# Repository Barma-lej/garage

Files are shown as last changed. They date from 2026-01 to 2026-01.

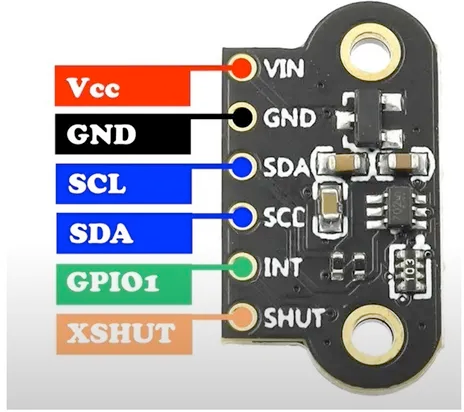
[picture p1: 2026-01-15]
docs/TOF400C-VL53L1X.png

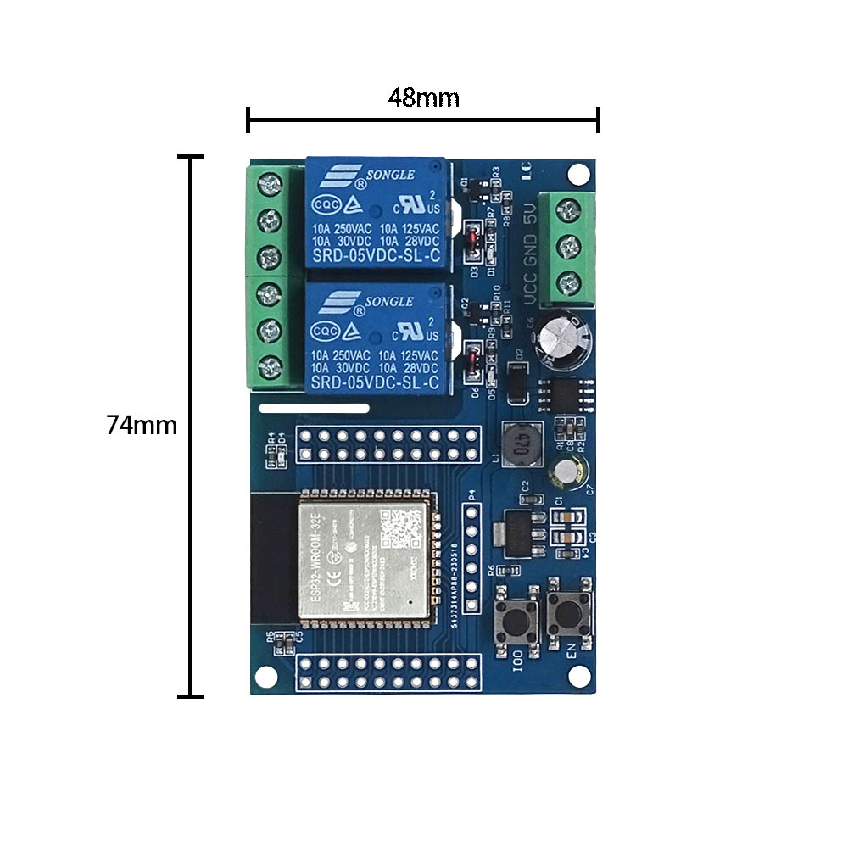
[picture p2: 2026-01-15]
docs/ESP32 Relay x2 (ESP32-WROOM-32E)-2.jpg

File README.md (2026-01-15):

# Smart Garage Door Controller with ESP32






This repository contains the firmware and configuration to transform any Hörmann Promatic 3 garage door opener into a smart, Home Assistant-controllable device. The system uses an **ESP32 Relay x2 (ESP32-WROOM-32E)** smart relay module to relay commands to the garage door drive unit while monitoring door position through a **TOF400C-VL53L1X** time-of-flight distance sensor and closed-position detection via a 24V optocoupler.

---

##  Key Capabilities
- **Remote Control**: Open, close, and ventilate (partial open) your garage door from Home Assistant
- **Position Feedback**: Real-time door position tracking using ToF sensor with millimeter precision
- **Safety Detection**: Closed position confirmation via hardware optocoupler
- **Local Integration**: Fully local control—no cloud dependency
- **Automation Ready**: Trigger automations based on door state and position
- **Voice Control**: Works with Home Assistant voice integrations (Alexa, Google Home)

---

## Hardware Requirements

| Component | Model/Specification | Purpose | Picture |
|---|---|---|---|
| Main controller | ESP32 Relay x2 (ESP32-WROOM-32E) | Main controller, WiFi, Relays (Open/close/airing garage door) | [ESP32 Relay x2 (ESP32-WROOM-32E)](docs/ESP32%20Relay%20x2%20(ESP32-WROOM-32E).jpg) |
| Position Sensor | 1-Channel 24V Optocoupler | Closed-state detection | [1-Channel 24V Optocoupler](docs/1%20Channel%20Way%20Optocoupler%2024V.jpg) |
| Distance Sensor | TOF400C-VL53L1X (I²C) | Position feedback, addr 0x29 | [TOF400C-VL53L1X](docs/TOF400C-VL53L1X.png) |

### Calibration Constants (from garage.yaml)
- **Closed position distance**: 2630 mm (door fully closed, sensor facing floor)
- **Open position distance**: 240 mm (door fully open)
- **Airing position**: 9% (0.09 × 100, triggered by Relay 2 + binary_airing flag)
- **Debounce time**: 50 ms (end_stop_bottom optocoupler)
- **Relay pulse duration**: 800 ms (impulse command activation)

### Optional Components
- 10 kΩ pull-up resistors (for ToF I²C SDA/SCL lines)
- **3D-printed enclosure and sensor mount** — See [3D Models](#3d-models) section for STL files and printing guide

---

## Installation

### 1. Hardware Assembly

#### Wiring Diagram

Wiring Diagram

```
Connections:
━━━━━━━━━━━━━━━━━━━━━━━━━━━━━━━━━━━━━━━━━━
GPIO16  → Relay 1 (Open/close command)
GPIO17  → Relay 2 (Ventilation command)
GPIO21  → TOF400C I²C SDA (optional with 10kΩ pull-up)
GPIO22  → TOF400C I²C SCL (optional with 10kΩ pull-up)
GPIO23  → LED anode (330Ω resistor to GND)
GPIO32  → 24V Optocoupler input (INPUT_PULLUP)
GND     → Common ground (all modules)
5V      → Relay module VCC, ESP32 5V
Vin     → Optional 5V USB power

Hörmann Promatic 3 Control:
━━━━━━━━━━━━━━━━━━━━━━━━━━━━━━━━━━━━━━━━━━
Relay 1 NO contacts  → Hörmann "Open" impulse terminals
Relay 1 NC contacts  → Hörmann "Close" impulse terminals
Relay 2 NO contacts  → Hörmann "Ventilation" impulse terminals
24V common           → Optocoupler cathode
```

---

## 3D Models

The project includes 3D-printable box in [`3D_model/`](3D_model/) directory.

---

## Firmware Upload

### Prerequisites
- **Home Assistant** instance running with ESPHome add-on installed
- **ESPHome Dashboard** web interface accessible (typically port 6052)
- **ESP32-WROOM-32E** connected via USB-C to the computer running Home Assistant
- **Secrets file** (`secrets.yaml`) with required credentials:
  ```yaml
  # secrets.yaml
  wifi_ssid: "Your_WiFi_Name"
  wifi_password: "Your_WiFi_Password"
  fallback_ap_password: "ApFallbackPassword"
  web_server_user: "admin"
  web_server_password: "YourWebPassword"
  garage_api: !secret api_encryption_key  # Generate via ESPHome
  ota_password: "YourOTAPassword"
  ```

### Step-by-Step Upload

1. **Prepare configuration file**
   - Copy the provided [`garage.yaml`](garage.yaml) to your Home Assistant configuration
   - Update GPIO pin assignments if different from your hardware
   - Edit substitution variables (friendly names, sensor calibration values)

2. **Access ESPHome Dashboard**
   - Open Home Assistant → Settings → Add-ons → ESPHome
   - Click "Open Web UI"
   - Ensure you see the ESPHome dashboard interface

3. **Create New Device**
   - Click "+ NEW DEVICE" button
   - Select "Continue"
   - Choose board type: **"ESP32 Dev Kit v1"** or similar
   - Enter device name: `garage` (or your preference)
   - Click "Next" → "Skip"

4. **Upload Configuration**
   - In dashboard, click the device card or **"Edit"** button
   - ⚠️ Copy `ap:` `password:` from auto-generated YAML to your `secrets.yaml` ⚠️
   - Replace the auto-generated YAML with your `garage.yaml` configuration
   - Click **"Save"**
   - ESPHome will validate the configuration

5. **Build & Upload Firmware**
   - Connect ESP32 via USB-C to your Home Assistant host
   - Click **"···" menu** → **"Upload"**
   - Select connection type: **"USB"** (or choose serial port)
   - Wait for compilation (~2–3 minutes) and upload
   - You should see: **`✓ Installed Successfully`**
   - Monitor serial logs during upload for any errors

6. **Verify Installation**
   - Disconnect USB cable (device will connect via WiFi)
   - In ESPHome dashboard, confirm device shows **"Online"** status
   - Go to Home Assistant → Settings → Devices & Services → ESPHome
   - You should see:
     - **Cover entity**: `cover.garage` (or `cover.tor`)
     - **Binary sensors**: `binary_sensor.geöffnet` (opened), `binary_sensor.lüftung` (airing)
     - **Sensors**: Position %, distance (mm), range status
   - Click the device to view detailed metrics

### Alternative: Manual Flashing (Advanced)

If USB connection is unavailable on your Home Assistant instance:

```bash
# Install esphome CLI
pip install esphome

# Compile firmware
esphome compile garage.yaml

# Flash via USB serial adapter
esphome run garage.yaml --device /dev/ttyUSB0 --upload-speed 460800

# View logs
esphome logs garage.yaml
```

---

## Usage

### Home Assistant Interface

Once discovered and configured, the following entities appear:

| Entity ID | Type | Function |
|---|---|---|
| `cover.tor_tor` (or `tor`) | Cover | Main door control with position slider (0–100%) |
| `button.tor_tor` | Button | Trigger open/close impulse |
| `button.tor_luftung` | Button | Trigger ventilation/airing impulse |
| `button.tor_restart` | Button | Restart device |
| `button.tor_safe_mode_boot` | Button | Safe mode boot |
| `binary_sensor.tor_geoffnet` | Binary Sensor | True when door is **open** (optocoupler inactive) |
| `binary_sensor.tor_luftung` | Binary Sensor | True when **ventilation mode** is active |
| `sensor.tor_position` | Sensor | Current door position in % (0=closed, 100=open) |
| `sensor.tor_distanz` | Sensor | Calibrate ToF distance in mm |
| `sensor.tor_raw_distanz` | Sensor | Raw ToF distance in mm |
| `sensor.tor_bereichsstatus` | Text Sensor | Range status (e.g., "Range Valid", "Signal Fail") |
| `sensor.tor_bereichsstatuswert` | Sensor | Range status (e.g., "1", "2") |
| `update.tor_firmware` | Update sensor | True when update is available |

### Control Methods

**Via Home Assistant UI:**
- Click the cover card to **open/close** the door
- Use the **position slider** for precise control:
  - Drag left (<5%) → **Close command**
  - Drag middle (10–20%) → **Ventilation** (9% opening)
  - Drag right (>95%) → **Open command**
- The **stop button** pauses movement

**Via Automations:**
```yaml
automation:
  - alias: "Close garage at night"
    trigger:
      platform: time
      at: "22:00:00"
    condition:
      - condition: state
        entity_id: cover.garage
        state: "open"
    action:
      - service: cover.close_cover
        target:
          entity_id: cover.garage

  - alias: "Open garage when arriving home"
    trigger:
      platform: state
      entity_id: person.john_doe
      to: "home"
    action:
      - service: cover.open_cover
        target:
          entity_id: cover.garage
```

**Via Scripts:**
```yaml
script:
  garage_ventilate:
    sequence:
      - service: cover.set_cover_position
        target:
          entity_id: cover.garage
        data:
          position: 15  # Triggers ventilation (9-20% range)

  garage_open:
    sequence:
      - service: cover.open_cover
        target:
          entity_id: cover.garage
```

**Via Voice Commands** (if Alexa/Google Home linked):
```
"Alexa, open my garage"
"Alexa, close my garage"
"Hey Google, open the garage door"
```

**Via MQTT** (if configured):
```bash
mosquitto_pub -h homeassistant.local -t home/garage/command -m "OPEN"
mosquitto_pub -h homeassistant.local -t home/garage/command -m "CLOSE"
mosquitto_pub -h homeassistant.local -t home/garage/command -m "VENTILATE"
```

---

## Configuration

### ESPHome YAML Configuration (garage.yaml)

The project includes a comprehensive [`garage.yaml`](garage.yaml) configuration file. Key sections:

#### 1. Substitutions (Customizable Variables)
```yaml
substitutions:
  name: garage
  room: Garage
  friendly_name: "Tor"  # German: "Gate"
  project_version: "2025.12.0"
  
  # GPIO Pin Assignments
  relay1_pin: GPIO16       # Open command
  relay2_pin: GPIO17       # Ventilation command
  status_led: GPIO23       # Status LED
  optocoupler_pin: GPIO32  # Closed-position sensor
  sda_pin: GPIO21          # I²C Data (ToF sensor)
  scl_pin: GPIO22          # I²C Clock (ToF sensor)
```

#### 2. WiFi Configuration
```yaml
wifi:
  ssid: !secret wifi_ssid
  password: !secret wifi_password
  fast_connect: true       # Connect quickly to known networks
  ap:
    ssid: "Garage Fallback Hotspot"
    password: !secret fallback_ap_password
```

#### 3. I²C Bus (TOF400C Sensor)
```yaml
i2c:
  - id: bus_a
    sda: GPIO21
    scl: GPIO22
    scan: true
    frequency: 400kHz  # Standard I²C frequency
```

#### 4. Cover Entity (Main Control)
```yaml
cover:
  - platform: template
    id: garage_door_cover
    name: "Tor"  # Display name
    device_class: garage
    has_position: true
    
    # Current position (0.0=closed, 1.0=open)
    lambda: |-
      return id(pos_sensor).state / 100.0;
    
    # Open command (Relay 1 pulse)
    open_action:
      - if:
          condition: lambda: 'return id(pos_sensor).state < 99.0;'
          then:
            - button.press: button_gate
    
    # Close command (Relay 1 pulse)
    close_action:
      - if:
          condition: binary_sensor.is_on: end_stop_bottom
          then:
            - button.press: button_gate
    
    # Position-based control
    position_action:
      - lambda: |-
          if (pos < 0.05) {
            // Close command
            if (id(end_stop_bottom).state)
              id(button_gate).press();
            id(binary_airing).publish_state(false);
          }
          else if (pos > 0.95) {
            // Open command
            if (id(pos_sensor).state < 95.0)
              id(button_gate).press();
            id(binary_airing).publish_state(false);
          }
          else if (pos > 0.10 && pos < 0.20) {
            // Ventilation (9% target)
            id(button_airing).press();
            id(binary_airing).publish_state(true);
          }
```

#### 5. Position Sensor (Lambda Calculation)
The position is calculated with priority logic:
```lambda
if (x != 0) return NAN;  // Validate range status

// 1. HARDWARE END-STOP (highest priority)
if (!id(end_stop_bottom).state)
  return 0.0;  // Door is closed

// 2. VENTILATION FLAG
if (id(binary_airing).state)
  return 9.0;  // Fixed ventilation position

// 3. DISTANCE-BASED CALCULATION
float max_dist = 2630.0;   // Closed (mm)
float min_dist = 240.0;    // Open (mm)
float calculated = ((max_dist - current_dist) / (max_dist - min_dist)) * 100.0;
return constrain(calculated, 0.0, 100.0);
```

### Configuration Customization

**Change GPIO pins:**
```yaml
substitutions:
  relay1_pin: GPIO4      # Change from GPIO16
  relay2_pin: GPIO5      # Change from GPIO17
  optocoupler_pin: GPIO35 # Change from GPIO32
```

**Adjust sensor calibration:**
```yaml
# In the position lambda function:
float max_dist = 2750.0;   # If your closed distance differs
float min_dist = 200.0;    # If your open distance differs
```

**Modify relay pulse duration:**
```yaml
button:
  - platform: output
    id: button_gate
    output: relay1
    duration: 1000ms  # Change from 800ms
```

**Enable debug logging:**
```yaml
logger:
  level: DEBUG  # More verbose output
  
text_sensor:
  - platform: template
    id: range_value
    name: "Range Status"
    disabled_by_default: false  # Show in UI
```

---

## Troubleshooting

### Device Not Connecting to WiFi
- **Symptom**: Fallback hotspot appears, no home network connection
- **Solution**:
  - Verify SSID and password in `secrets.yaml` are correct
  - Check WiFi signal strength in garage (RSSI > -75 dBm ideal)
  - Restart ESPHome device via Home Assistant → Devices → Restart
  - Check logs: ESPHome dashboard → Logs

### Distance Sensor Returns NAN or Invalid Readings
- **Symptom**: ToF sensor shows "NAN" in position sensor, range status is not 0
- **Solution**:
  - Verify I²C connections (GPIO21 SDA, GPIO22 SCL)
  - Check for 10kΩ pull-up resistors on SDA/SCL lines
  - Clean lens of TOF400C sensor (dust reduces accuracy)
  - Ensure sensor is perpendicular to garage door
  - Confirm sensor address is 0x29: ESPHome dashboard → Logs → "i2c: Found device at 0x29"
  - Test I²C with: `esphome logs garage.yaml | grep -i i2c`

### Relay Not Triggering Door
- **Symptom**: Door doesn't move when pressing open/close button
- **Solution**:
  - Verify relay wiring to Hörmann control terminals
  - Test relays independently with multimeter:
    - Touch relay coil pins → should show 5V when active
    - Measure NO/NC contacts → should toggle continuity
  - Increase relay pulse duration (currently 800ms):
    ```yaml
    duration: 1200ms  # Try longer pulse
    ```
  - Verify GPIO16 and GPIO17 are not used elsewhere
  - Check Hörmann manual for impulse timing requirements

### Optocoupler Not Detecting Closed Position
- **Symptom**: Door closed but binary_sensor.geöffnet shows "ON" (open)
- **Solution**:
  - Verify 24V optocoupler wiring:
    - Cathode (-) to 24V common
    - Anode (+) to Hörmann closed-position circuit
  - Check GPIO32 continuity with multimeter
  - Verify INPUT_PULLUP mode: `inverted: false` in YAML
  - Increase debounce time if signal is unstable:
    ```yaml
    filters:
      - delayed_on_off: 100ms  # Change from 50ms
    ```

### Door State Not Updating in Home Assistant
- **Symptom**: Position slider doesn't reflect actual door movement
- **Solution**:
  - Increase sensor update interval:
    ```yaml
    update_interval: 500ms  # Change from 1s
    ```
  - Verify `pos_sensor` is receiving values (not NAN)
  - Check Home Assistant logs: Settings → System → Logs
  - Force entity refresh: Developer Tools → States → Restart device

---

## Contributing

Contributions are welcome! Please follow these guidelines:

1. **Fork** the repository
   ```bash
   git clone https://github.com/YOUR_USERNAME/garage.git
   cd garage
   ```

2. **Create a feature branch**
   ```bash
   git checkout -b feature/your-improvement
   # e.g., git checkout -b feature/multi-sensor-fusion
   ```

3. **Make your changes**
   - Modify YAML configuration or add new features
   - Update documentation with clear comments
   - Test thoroughly with real Hörmann Promatic 3 hardware

4. **Commit with clear messages**
   ```bash
   git commit -am "Add multi-sensor redundancy for position detection"
   ```

5. **Push and submit pull request**
   ```bash
   git push origin feature/your-improvement
   ```
   - Provide detailed description of changes
   - Include before/after testing results
   - Reference any related issues

### Testing Requirements
Before submitting a PR:
- [ ] Verify door opens and closes correctly
- [ ] Test ventilation mode (9% position)
- [ ] Confirm optocoupler detects closed position
- [ ] Check WiFi reconnection after dropout
- [ ] Test OTA firmware update functionality
- [ ] Verify no sensor NAN errors in normal operation

---

## License

This project is licensed under the **MIT License**. See [LICENSE](LICENSE) file for details.

You are free to use, modify, and distribute this software for personal and commercial purposes, with attribution to the original author (Barma-lej).

---

## Support & Community

- **GitHub Issues**: [Report bugs](https://github.com/Barma-lej/garage/issues) or request features
- **Discussions**: [GitHub Discussions](https://github.com/Barma-lej/garage/discussions) for Q&A
- **ESPHome Docs**: [Official Documentation](https://esphome.io)
- **Home Assistant Community**: [Community Forums](https://community.home-assistant.io)
- **Hörmann Promatic 3 Manual**: [Manual DE](docs/hoermann-promatic-3-anleitung.pdf)

---

## Safety Disclaimer

⚠️ **IMPORTANT SAFETY INFORMATION**

This system interfaces with **moving machinery**. Proper installation and operation are critical:

### Before Installation
- [ ] Read Hörmann Promatic 3 manual thoroughly
- [ ] Ensure you have electrical installation competence (or hire professional)
- [ ] Verify local electrical and building codes compliance
- [ ] Check garage door is in good mechanical condition

### During Operation
- [ ] All original safety features must remain **fully functional**
- [ ] Emergency manual override must **always be accessible**
- [ ] Perform regular testing of:
  - [ ] Door movement and reversal
  - [ ] Closed-position detection
  - [ ] Obstacle detection (if present)
  - [ ] Emergency stop functionality
- [ ] Never allow children unsupervised near the door
- [ ] Do not modify relay impulse timing without testing

### Liability
The authors assume **no liability** for:
- Injury or property damage
- Improper installation or electrical work
- Failure of safety features
- Unauthorized modifications

---

**💡 Tip:** If you like this project just buy me a cup of ☕️ or 🥤:

Buy Me A Coffee (https://www.buymeacoffee.com/barma)

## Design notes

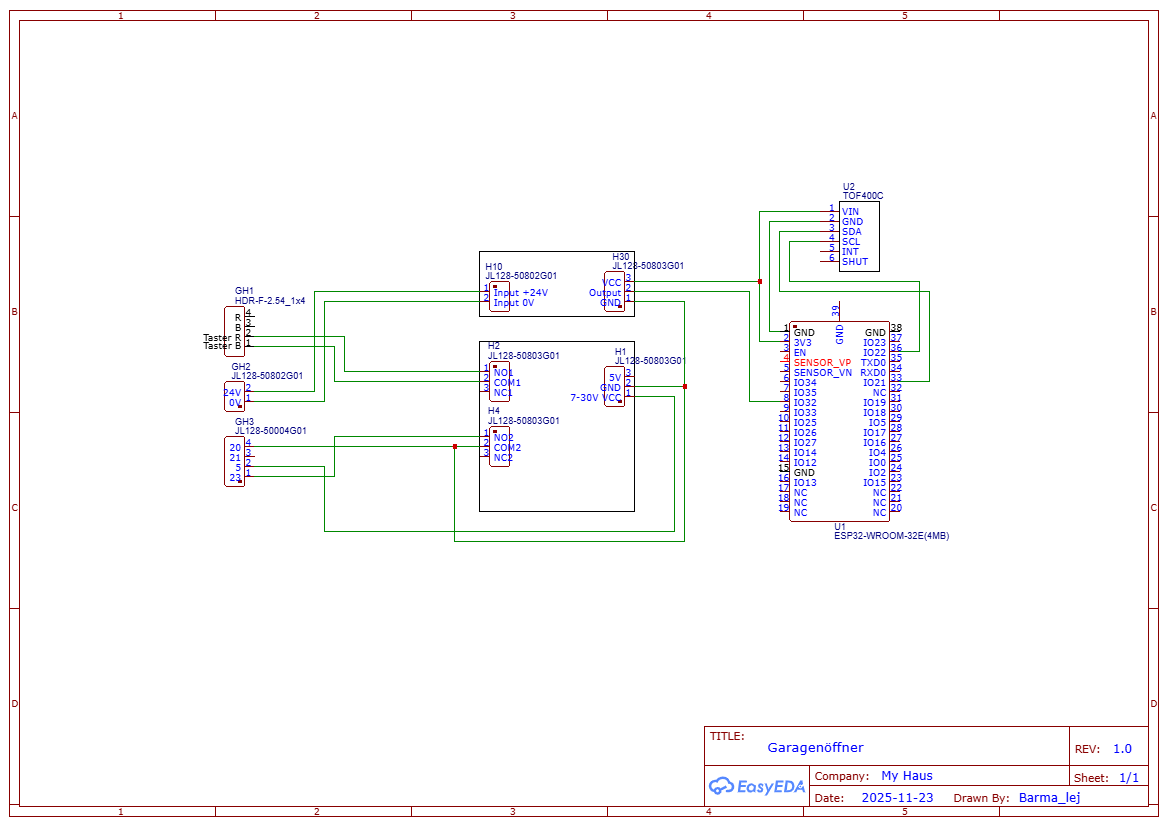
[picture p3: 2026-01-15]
docs/Schematic_Garage_2025-12-16 (ESP32-WROOM-32E Relay x2).png

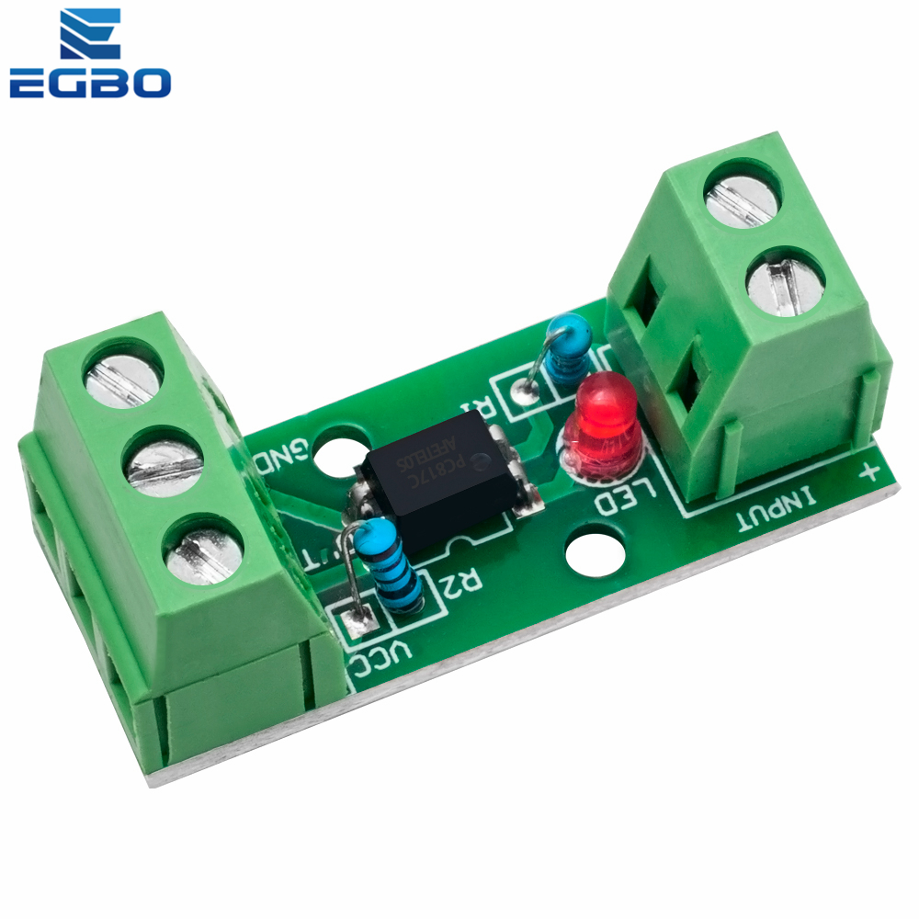
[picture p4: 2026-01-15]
docs/1 Channel Way Optocoupler 24V.jpg

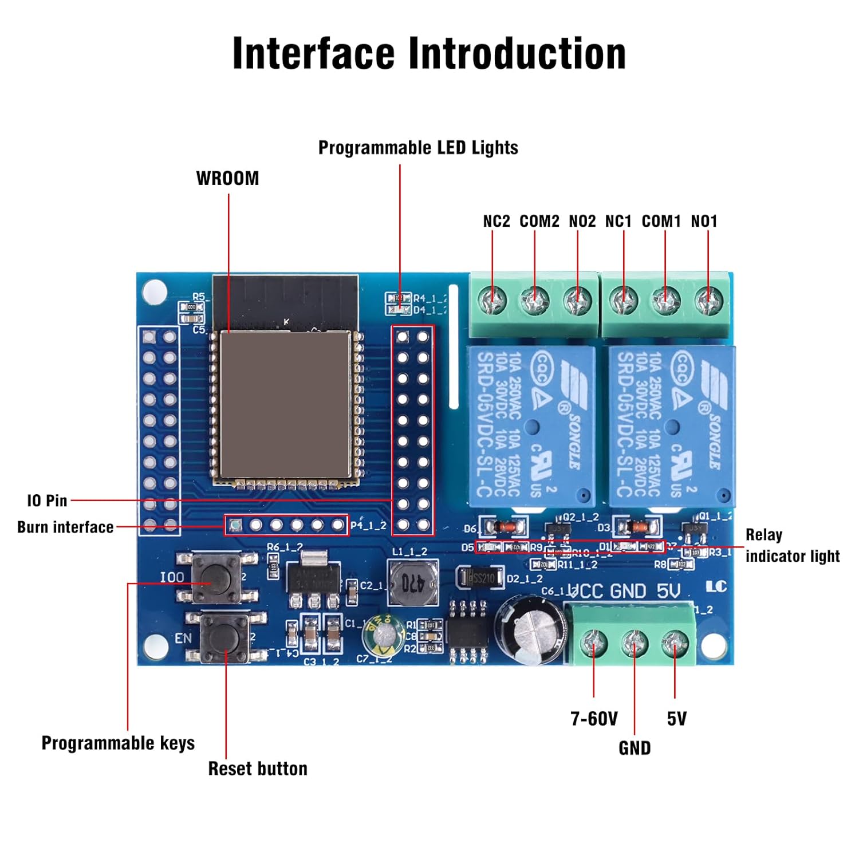
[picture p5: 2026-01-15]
docs/ESP32 Relay x2 (ESP32-WROOM-32E).jpg

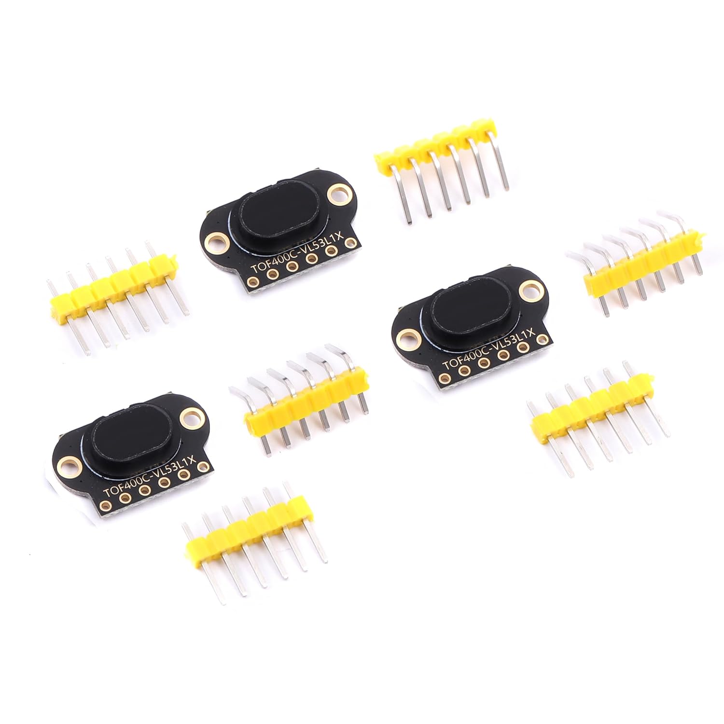
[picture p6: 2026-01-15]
docs/TOF400C-VL53L1X.jpg

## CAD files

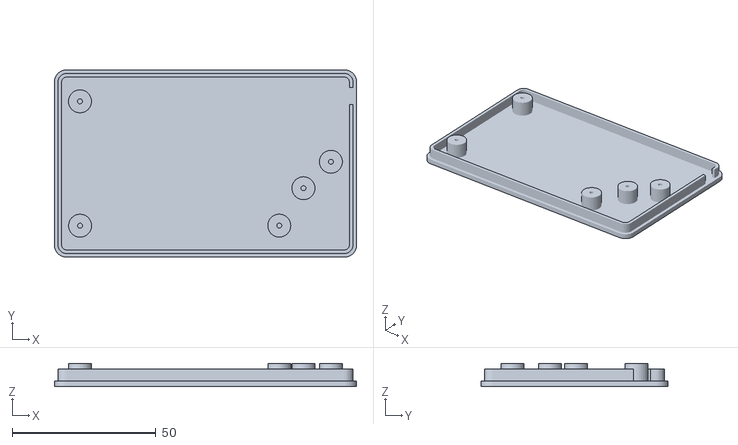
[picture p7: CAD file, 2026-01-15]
3D_model/Garagentorbox_bottom.stl
105.0 x 65.0 x 8.00

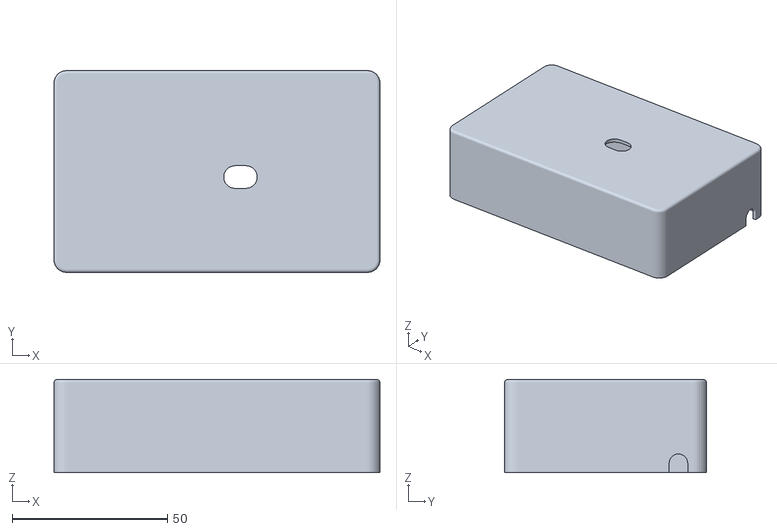
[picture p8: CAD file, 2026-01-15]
3D_model/Garagentorbox_top.stl
105.0 x 65.0 x 30.0

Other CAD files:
3D_model/ESP32_Relay_2x_Garage.f3z

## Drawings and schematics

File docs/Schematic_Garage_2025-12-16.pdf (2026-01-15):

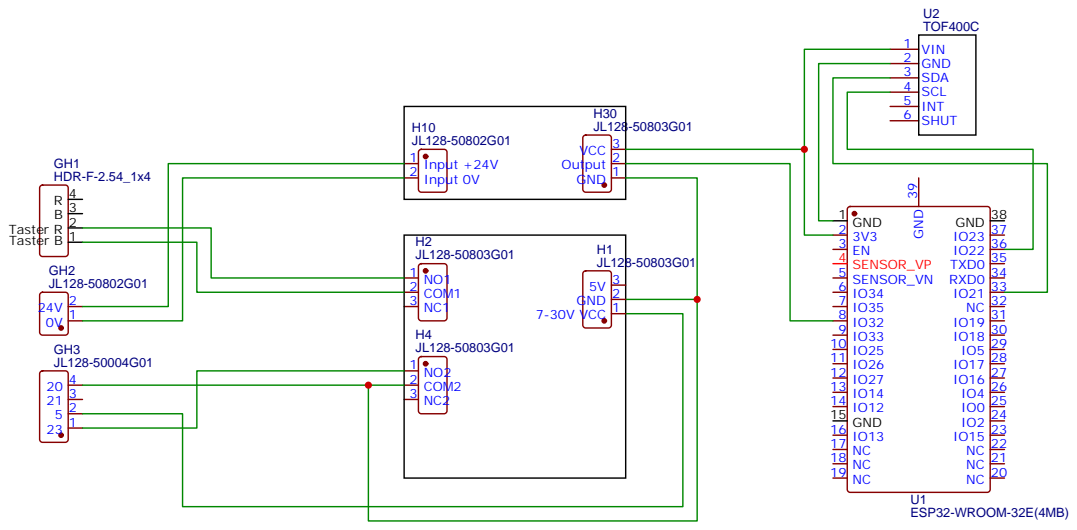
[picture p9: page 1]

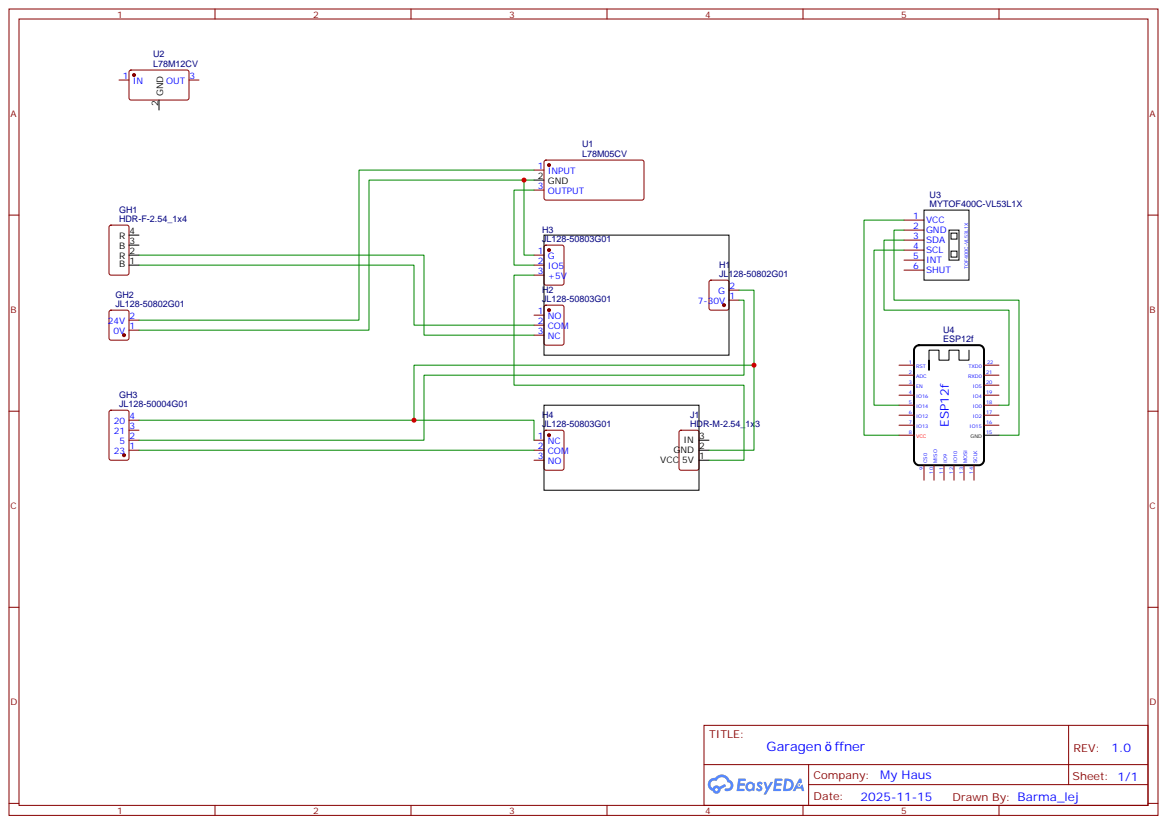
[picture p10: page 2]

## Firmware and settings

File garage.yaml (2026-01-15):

# Garagentorsteuerung
#
# Garagentorsteuerung mit der Positionskontrolle von Garagentoren
# © Barma-lej
#

substitutions:
  # device_name: garagegate
  name: garage
  room: Garage
  friendly_name: Tor
  project_version: "2025.12.0"
  device_description: "Garagentorsteuerung mit der Positionskontrolle von Garagentoren"

  button_gate: "Tor"
  button_airing: "Lüftung"

  binary_airing: "Lüftung"
  binary_opened: "Geöffnet"

  sensor_position: "Position"
  sensor_raw_distance: "RAW Distanz"
  sensor_distance: "Distanz"
  sensor_range_status_value: "Bereichsstatuswert"
  sensor_range_status: "Bereichsstatus"

  # Webserver credentials
  web_username: !secret web_server_user
  web_password: !secret web_server_password

  # Define the GPIO pins
  relay1_pin: GPIO16
  relay2_pin: GPIO17
  status_led: GPIO23
  optocoupler_pin: GPIO32

  # Laser Ranging Sensor Module TOF400C-VL53L1X
  sda_pin: GPIO21 # TOF400C-VL53L1X PIN 3
  scl_pin: GPIO22 # TOF400C-VL53L1X PIN 4


external_components:
  - source: github://mrtoy-me/esphome-vl53l1x@main
    components: [ vl53l1x ]
    refresh: 0s

esphome:
  name: ${name}
  friendly_name: ${friendly_name}
  comment: ${device_description}
  name_add_mac_suffix: false
  project:
    name: "barma-lej.${name}"
    version: ${project_version}
  # on_boot:
  #   - lambda: |-
  #       id(my_ota).set_auth_password("");

esp32:
  board: esp32dev
  framework:
    type: esp-idf

# Enable logging
logger:

# Enable Home Assistant API
api:
  encryption:
    key: !secret garage_api

ota:
  - platform: esphome
    # id: my_ota
    password: !secret ota_password

wifi:
  ssid: !secret wifi_ssid
  password: !secret wifi_password

  # Enable fallback hotspot (captive portal) in case wifi connection fails
  ap:
    ssid: "Garage Fallback Hotspot"
    password: !secret fallback_ap_password

captive_portal:

web_server:
  id: esphome_web_server
  version: 3
  port: 80
  auth:
    username: '${web_username}'
    password: '${web_password}'

# https://esphome.io/components/i2c.html
i2c:
  - id: bus_a
    sda: '${sda_pin}'
    scl: '${scl_pin}'
    scan: true
    # VL53L1X, 0x29
    # Higher data rates reduce the time required for read/write operations, which
    # should prevent the "component took a long time for an operation" warning in the logs.
    frequency: 400kHz

# Example configuration entry
output:
  - platform: gpio
    pin: ${relay1_pin}
    id: relay1
  - platform: gpio
    pin: ${relay2_pin}
    id: relay2

button:
  # Открываем/закрываем гараж
  - platform: output
    id: button_gate
    name: ${button_gate}
    output: relay1
    duration: 800ms
    icon: mdi:garage-variant
    on_press:
      then:
        # Устанавливаем состояние binary_sensor binary_airing в OFF (false)
        - binary_sensor.template.publish:
            id: binary_airing
            state: OFF

  # Приоткрываем гараж
  - platform: output
    id: button_airing
    name: ${button_airing}
    output: relay2
    duration: 800ms
    icon: mdi:garage-open-variant
    on_press:
      then:
        # Устанавливаем состояние binary_sensor binary_airing в ON (true)
        - binary_sensor.template.publish:
            id: binary_airing
            state: ON

  # Restart the ESP
  - platform: restart
    name: "${friendly_name} Restart"
    disabled_by_default: true

  # Boot in Safe mode
  - platform: safe_mode
    name: "${friendly_name} Safe Mode Boot"
    entity_category: diagnostic
    disabled_by_default: true

binary_sensor:
  # Optocoupler
  # Gate is opened - True
  - platform: gpio
    id: end_stop_bottom
    name: ${binary_opened}
    device_class: garage_door
    pin:
      number: ${optocoupler_pin}
      mode: INPUT_PULLUP
      inverted: false
    filters:
      - delayed_on_off: 50ms
    on_state:
      - if:
          condition:
            binary_sensor.is_off: end_stop_bottom  # Ворота ЗАКРЫТЫ
          then:
            # Устанавливаем состояние binary_sensor binary_airing в OFF (false)
            - binary_sensor.template.publish:
                id: binary_airing
                state: OFF
            # Установка позиции сенсора pos_sensor на 0
            - sensor.template.publish:
                id: pos_sensor
                state: 0


  - platform: template
    id: binary_airing
    name: ${binary_airing}
    device_class: running
    trigger_on_initial_state: false
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

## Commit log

2026-01-15 Revise README for Smart Garage Door Controller
    Updated README to provide detailed project information, capabilities, hardware requirements, installation instructions, and troubleshooting tips for the Smart Garage Door Controller using ESP32.
2026-01-15 Revise README for GPIO connections and assembly steps
    Updated GPIO pin connections and clarified optional components in the README. Removed detailed assembly steps and 3D model descriptions to streamline the document.
